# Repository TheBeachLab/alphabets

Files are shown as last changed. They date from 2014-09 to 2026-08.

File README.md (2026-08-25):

<!-- SPDX-FileCopyrightText: 2014-2026 The Beach Lab <https://beachlab.org> -->
<!-- SPDX-License-Identifier: MIT -->
# Alphabets

Welcome to the public repository of the second edition (**V2**) of Alphabets,
an open-source modular split-flap display. Each module shows one character, and
modules can be arranged together to display messages. For information about
the first release from 2014, see [V1](V1). Please also check the [YouTube videos](https://www.youtube.com/playlist?list=PLKDpiLmgp6EuLGCovD-QFxrmyNdrbUmKX)

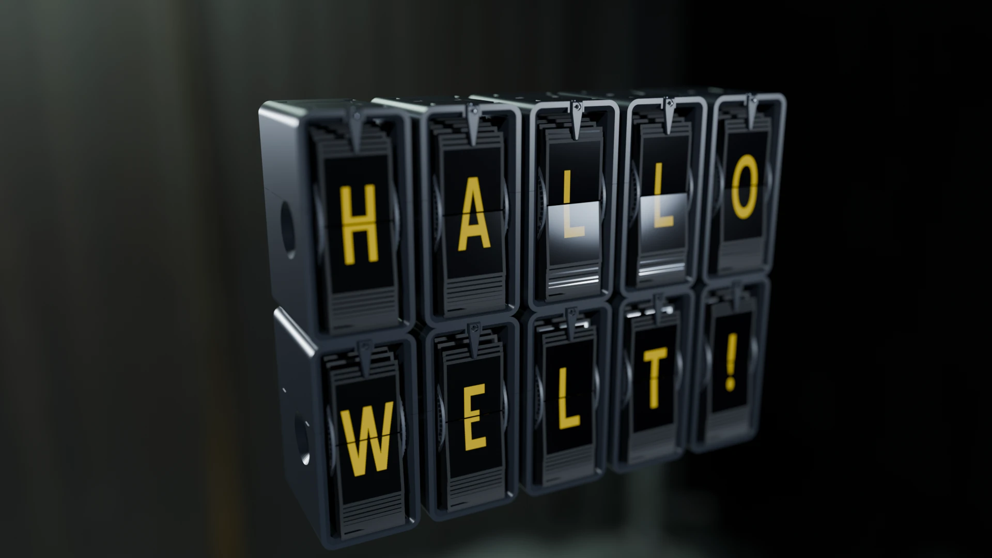
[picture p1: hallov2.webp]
Blender render of ten modular Alphabets V2 split-flap units displaying HALLO WELT!


## The two V2 versions

In this repository you will find two V2 versions: **V2 Prototype** and
**V2 Final**. They are complete, incompatible physical profiles; each has its
own stickers, cards, drum and enclosure, and their parts must not be mixed.

- **V2 Prototype** is for myself. A while ago I printed ten module sticker sets in Dubai and I am using those for prototyping. Of course might use those too. When new V2 Final sticker and card batches are available I will no longer develop this variant.
- **V2 Final** is the supported target for new batches. The expanded character
  map for the German-speaking DACH region (Germany, Austria and Switzerland)
  and Nordic languages requires more vertical artwork space, so this version
  uses taller stickers and cards with a matching drum and enclosure.

See the [V2 physical variants](V2/Hardware/variants/README.md) for the exact parts
and dimensions belonging to each version.

> [!WARNING]
> **UNDER HEAVY DEVELOPMENT — NOT READY FOR USE OR FABRICATION.**
> The V2 Final enclosure has a recorded print check, but the complete mechanism,
> Prototype enclosure, electronics and production process are not physically
> validated. Do not order, print, cut or assemble multiple parts without
> checking the dimensions and validating one complete module. Never mix files
> between the Prototype and Final folders.

## What's new in V2

* 120% pure awesomeness.
* 64 cards with international character set.
* Custom colors: Request custom colored modules and custom characters.
* Build your own or order a kit or ready built module.
* No more gears, direct drive motor
* 3D Printed enclosure
* Entirely designed with widely adopted open source software.
* Assemble in multiple layouts of rows and columns.
* Networked electronics: Connect from one to infinite(*) modules together.
* Web based interface: Control your modules interactively with your web browser.

(*) Not really

## TOC

This table of contents documents V2 Final.

- Mechanical
  - [Cards](doc/cards.md)
  - [Stickers](doc/stickers.md)
  - [Drum](doc/drum.md)
  - [Enclosure](doc/enclosure.md)
- Electronics
  - [Motors](doc/motors.md)
  - [Module Board](doc/module-board.md)
  - [Motherboard](doc/motherboard.md)
  - [Chaining and cables](doc/chaining-and-cables.md)
- Software and Architecture
  - [Protocol](doc/protocol.md)
  - [Module embedded software](doc/module-firmware.md)
  - [Motherboard embedded software](doc/motherboard-firmware.md)
  - [Web interface](doc/web-interface.md)

See the [documentation index](doc/README.md) for the same guide with the
current implementation status of each part.

## License

Except where a file or directory states otherwise, Alphabets' original source
code, firmware, electronics designs, mechanical designs, documentation, and
generated project artifacts are licensed under the [MIT License](LICENSE).
Copyright (c) 2014-2026 [The Beach Lab](https://beachlab.org).

Every commentable file carries a copyright and SPDX license header. JSON,
VS Code workspace, and native KiCad files embed the same fields as document
data so the declaration travels with them. Blender, FreeCAD, OpenType, SVG,
PDF, PNG, JPEG, ZIP, STEP, DXF, binary STL, Gerber, and Excellon files also use
embedded metadata or standard comments and do not need duplicate sidecars.
Only formats without a safely interoperable embedded mechanism use an adjacent
`.license` file. Legacy and bundled third-party sources retain their actual
notices and licenses.

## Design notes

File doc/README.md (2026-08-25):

<!-- SPDX-FileCopyrightText: 2014-2026 The Beach Lab <https://beachlab.org> -->
<!-- SPDX-License-Identifier: MIT -->
# Alphabets V2 guide

[← Project README](../README.md) · [Start with the cards →](cards.md)

Alphabets V2 is an open-source modular split-flap display. Each module shows one
character by turning a drum of 64 cards. Modules can be arranged together to
display complete messages.

## The two V2 versions

This repository contains **V2 Prototype** and **V2 Final**. Each is a complete
physical profile with its own stickers, cards, drum and enclosure, so their
parts cannot be mixed. Prototype uses the ten existing sticker sets printed in
Dubai. Final is the supported target for new batches; its expanded character
map for the German-speaking DACH region (Germany, Austria and Switzerland) and
Nordic languages requires taller artwork, stickers and cards. Prototype support
ends when new Final sticker and card batches are available. The
[physical variants contract](../V2/Hardware/variants/README.md) records the
exact dimensions and files that belong together.

The rest of this guide explains **V2 Final** in the order that information
moves through the display: a message enters the controller, travels through the
module chain, and each module turns its drum until the requested card is
visible.

> [!WARNING]
> V2 is under development. The V2 Final enclosure has a recorded print check,
> but the complete mechanism, Prototype enclosure, electronics and production
> process are not physically validated. Make fit samples and validate one
> complete module before ordering multiple parts.

## Mechanical

1. [Cards](cards.md) — the 64 moving flaps that carry the characters.
2. [Stickers](stickers.md) — the printed character artwork applied to the cards.
3. [Drum](drum.md) — the rotating structure that holds the cards in order.
4. [Enclosure](enclosure.md) — the two-part body around one complete module.

## Electronics

1. [Motors](motors.md) — how one motor advances one drum.
2. [Module board](module-board.md) — the small controller fitted to each module.
3. [Motherboard](motherboard.md) — the planned controller for the complete display.
4. [Chaining and cables](chaining-and-cables.md) — the six-wire ring between boards.

## Software and architecture

1. [Protocol](protocol.md) — the two communication layers and what they carry.
2. [Module embedded software](module-firmware.md) — firmware that moves and homes one drum.
3. [Motherboard embedded software](motherboard-firmware.md) — planned layout and chain control.
4. [Web interface](web-interface.md) — planned user interface for sending text.

## What is implemented now?

| Area | Current repository status |
| --- | --- |
| Cards, stickers, drum, enclosure | Matched Prototype and Final sources and manufacturing exports exist; complete physical validation is still required |
| Motor | A 28BYJ-48 reference model and firmware defaults exist; the real assembly still needs validation |
| Module board | Editable ATtiny1624 KiCad design and fabrication exports exist |
| Module firmware | ATtiny1624 firmware and host-side tests exist |
| Motherboard hardware and firmware | Protocol responsibilities are defined; implementation is not in the repository yet |
| Web interface | Message protocol is defined; implementation is not in the repository yet |

V2 Prototype and V2 Final parts must never be mixed.

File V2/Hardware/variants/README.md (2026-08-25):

<!-- SPDX-FileCopyrightText: 2014-2026 The Beach Lab <https://beachlab.org> -->
<!-- SPDX-License-Identifier: MIT -->
# V2 physical variants

`variants.json` is the authoritative contract that prevents parts from the two
incompatible V2 builds being mixed. A character order is inseparable from its
sticker sheet, card, drum spacing and enclosure source.

V2 Prototipo supports prototyping with the ten existing sticker sets printed in
Dubai. V2 Definitivo is the target profile for new batches. Its expanded DACH
and Nordic character map needs taller artwork, so it uses matched taller
stickers and cards together with the corresponding drum and enclosure.
Prototipo remains usable while the existing sets are in service, but support
ends when new Definitivo sticker and card batches are available.

| Variant | Character preset | Sticker / halves | Card | Drum inner / outer width | Enclosure |
| --- | --- | --- | --- | --- | --- |
| **V2 Prototipo** | `demo-64` | two 50 × 40 mm cuts, 1.8 mm gap | 55 × 43 mm, all visible | 56 / 60.3 mm | one-piece, open-front/rear CadQuery source; physical fit pending |
| **V2 Definitivo** | `international-64` | two 45 × 45.5 mm cuts, 1.8 mm gap | 50 × 48 mm, all visible | 51 / 55.3 mm | current two-piece, open-rear CadQuery source |

Both variants leave a 2.5 mm placement margin at each lateral edge. The sticker
is aligned with the hinge/tab edge, not the opposite free edge. The whole card
face remains visible, with the uncovered strip at the free edge: 3 mm on the
prototype and 2.5 mm on the definitive card.

The `1.8 mm` center gap is part of the printed artwork layout, not a third
sticker. The artwork remains continuous through it, while the cutter receives
two independent half-card rectangles. Typography uses one safe uniform base
scale against the locked sticker width and height, without squeezing or
stretching individual glyphs. W uses the exact Prototype Blue Highway
Condensed outline stored in `cutprint.svg`, with horizontal factor `0.95902088`.
International 64 uses the actual Condensed Æ outline and
a small width adjustment so its final visible width exactly matches W. Both
physical profiles use the exact condensed `%` outline from the Prototype.
The colored background extends `2 mm` past the outer cutter edges without
changing either finished sticker rectangle, preventing white slivers from a
small print/cut registration shift.

## Sticker sheets

V2 Prototype uses the existing
[`cut-print/cutprint.svg`](../Prototype/stickers/cut-print/cutprint.svg) file.
It contains the print artwork and cutter lines used for the ten Dubai sticker
sets.

Generate V2 Final sheets with the locked Definitivo profile:

```sh
python3 V2/Hardware/Final/stickers/generate_stickers.py \
  --variant definitive \
  --color-preset black-white \
  --output-svg /tmp/international-64-definitive-45x91.svg
```

The Final sticker generator records the physical variant in its JSON
manufacturing manifest and rejects an incompatible width or height override.

## Sources and fabrication status

The Prototype CadQuery package is under
[`../Prototype/mechanical`](../Prototype/mechanical/README.md). It defines one
matched card, sticker, drum, pawl and enclosure profile. The Prototype
enclosure is **not yet physically validated**. This profile is supported only
for the existing prototyping batches described above.

Rebuild the Prototype package with:

```sh
cd V2/Hardware/Prototype/mechanical
make check
```

The Final variant is the supported target for new sticker and card batches. Its
enclosure is confirmed against the 2026-08-23 physical print. Its card
and 64-position drum are generated from
`V2/Hardware/Final/mechanical/alphabets_cad/`, and its sole current enclosure is
the capture-fitted pipeline under
`generated/captured-enclosure/`. Further fit observations are required before
a production run.

Both card substrates are 0.5 mm. A 0.1 mm sticker is applied to each face,
making the covered area 0.7 mm thick; the opposite free-edge strip, lateral
margins and tab extensions remain bare at 0.5 mm.

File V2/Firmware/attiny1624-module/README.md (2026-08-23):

<!-- SPDX-FileCopyrightText: 2014-2026 The Beach Lab <https://beachlab.org> -->
<!-- SPDX-License-Identifier: MIT -->
# ATtiny1624 module firmware

This AVR C firmware implements revision 2 of the controller-to-module
[`protocol`](../../Protocol/PROTOCOL.md) for a 5 V ATtiny1624-SSU module.

## Implemented behavior

- Hardware `SPI0` client on `PA1/MOSI`, `PA2/MISO`, `PA3/SCK`, and `PA4/SS`.
- Byte forwarding through an arbitrary-length physical module chain.
- `0x00`, `0x01..0x40`, and automatic-home `0x41` commands.
- Active-low position-0 sensor on `PA5` with the internal pull-up enabled.
- Edge-qualified and sample-confirmed homing from either initial sensor state
  with a two-revolution travel limit.
- Present, ready, and current-position status reporting.
- Non-blocking forward-only half-step motion on `PB0..PB3` using `TCB0`.
- Wear-levelled EEPROM persistence with invalidation before movement.
- Idle sleep while SPI, latch, and motor interrupts remain serviceable.

All modules use the same binary. Chain order determines display position.

## Pin assignment

| Function | Port | SOIC-14 pin |
| --- | --- | --- |
| `LATCH / SPI0 SS` | `PA4` | 2 |
| `HOME`, active low | `PA5` | 3 |
| Motor phase 4 | `PB3` | 6 |
| Motor phase 3 | `PB2` | 7 |
| Motor phase 2 | `PB1` | 8 |
| Motor phase 1 | `PB0` | 9 |
| `UPDI` | `PA0` | 10 |
| `DATA_IN / SPI0 MOSI` | `PA1` | 11 |
| `DATA_OUT / SPI0 MISO` | `PA2` | 12 |
| `CLOCK / SPI0 SCK` | `PA3` | 13 |

The home input expects a contact or open-drain sensor between `PA5` and ground.
The motor outputs drive a ULN2003-style input stage, not the motor coils
directly. Keep the UPDI pad accessible on the production PCB.

## Position recovery

On first boot or after an interrupted movement, position commands remain
disabled until the controller sends `0x41`. The module advances forward until
it observes a fresh inactive-to-active home transition, stores position 0, and
then reports ready. If the transition is not found within two configured drum
revolutions, the phases are released and the module remains unreferenced.

The EEPROM journal contains 32 four-byte records. The firmware appends an
unknown-position record before energizing the motor and appends the completed
position after stopping. The commit byte is written last so an interrupted
write cannot become the active record.

## Motor configuration

The defaults target a 5 V 28BYJ-48 with a ULN2003-style driver:

| Setting | Default | Meaning |
| --- | --- | --- |
| `F_CPU` | `20000000UL` | Factory 20 MHz oscillator with its prescaler disabled |
| `MOTOR_HALF_STEPS_PER_REVOLUTION` | `4096UL` | Tunable output-shaft half-steps per drum revolution |
| `MOTOR_STEP_HZ` | `500UL` | Half-step rate |
| `MOTOR_REVERSED` | `0` | Set to `1` to reverse the phase sequence |
| `HOMING_MAX_REVOLUTIONS` | `2UL` | Maximum home-search travel |
| `HOME_ACTIVE_CONFIRM_STEPS` | `2u` | Consecutive active samples required at home |

The firmware distributes `MOTOR_HALF_STEPS_PER_REVOLUTION` across all 64 drum
positions, including values that are not divisible by 64. Confirm the actual
step count and direction on the assembled mechanism.

Override settings through `CPPFLAGS`, for example:

```sh
make CPPFLAGS='-DF_CPU=20000000UL -DMOTOR_HALF_STEPS_PER_REVOLUTION=4076UL -DMOTOR_REVERSED=1'
```

## Build and test

Run the portable state-machine and ring tests with the host compiler:

```sh
make test
```

Build the ATtiny1624 ELF and Intel HEX with AVR GCC:

```sh
make
```

With the keg-only Homebrew AVR GCC 15 package used for repository validation:

```sh
PATH="/opt/homebrew/opt/avr-gcc@15/bin:$PATH" make check
```

The resulting image is
`build/alphabets-v2-attiny1624-module.hex`.

Flash it through the board's UPDI connection with an avrdude programmer that
supports the ATtiny1624, for example an Atmel-ICE:

```sh
make flash PROGRAMMER=atmelice_updi
```

Use `AVRDUDE_FLAGS` for programmer-specific port settings. The firmware selects
the undivided clock at runtime and expects the factory `OSCCFG.FREQSEL=0x2`
[setting for 20 MHz](https://onlinedocs.microchip.com/oxy/GUID-7056F141-DF07-46C5-A4B8-97EB46E9B945-en-US-12/GUID-7BAFED36-9153-4AA6-BB14-C0434476E4F6.html).
After a chip erase that clears EEPROM, run `0x41` once to establish the drum
reference.

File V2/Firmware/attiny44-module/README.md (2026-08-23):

<!-- SPDX-FileCopyrightText: 2014-2026 The Beach Lab <https://beachlab.org> -->
<!-- SPDX-License-Identifier: MIT -->
# ATtiny44A module firmware

This AVR C firmware implements the controller-to-module protocol in
[`prototype protocol`](../../Protocol/PROTOCOL_V1_ATTINY44.md) for the
[`ATtiny44 ring board`](../../Hardware/Prototype/electronics/attiny44-ring)
board.

## Implemented behavior

- ATtiny44A USI three-wire slave on `PA6/DI`, `PA5/DO`, and `PA4/USCK`.
- `PA7` pin-change interrupt for the active-low frame `LATCH`.
- Byte forwarding through an arbitrary-length physical module chain.
- Rejection of frames that end between byte boundaries.
- `0x00`, `0x01..0x40`, and `0x41` command handling.
- Present, ready, and current-position status byte generation.
- Non-blocking forward-only half-step motion on `PA0..PA3`.
- Timer-driven movement while USI frames continue to be serviced.
- Wear-levelled EEPROM persistence of the last fully reached position.
- EEPROM invalidation before movement, so interrupted motion requires a new
  manual position-0 reference instead of reporting a stale position as ready.

All modules use the same binary. Chain order determines display position.

## Position reference on the current PCB

The current `attiny44-ring` PCB leaves `PB2/HOME` unconnected. On first boot,
after interrupted motion, or after mechanically changing a drum:

1. Leave the module powered and stationary.
2. Align the drum so its installed character position 0 is visible.
3. Send command `0x41` to that module.
4. Wait until its status reports `ready = 1` at position 0.

The calibration command records the reference in EEPROM without moving the
motor. Position commands are ignored while the reference is unknown.

Position state uses a 32-record EEPROM journal. The firmware appends an
unreferenced record before energizing the motor and appends the completed
position afterward. The commit byte is written last, so a partially written
record is ignored at the next boot.

## Motor configuration

The defaults target a 5 V 28BYJ-48 with its ULN2003-style driver:

| Setting | Default | Meaning |
| --- | --- | --- |
| `F_CPU` | `8000000UL` | Internal CPU clock after clearing `CLKPR` |
| `MOTOR_HALF_STEPS_PER_REVOLUTION` | `4096UL` | Tunable output-shaft half-steps per drum revolution |
| `MOTOR_STEP_HZ` | `500UL` | Half-step rate |
| `MOTOR_REVERSED` | `0` | Set to `1` to reverse the phase sequence |

The firmware distributes `MOTOR_HALF_STEPS_PER_REVOLUTION` across all 64 drum
positions, including values that are not divisible by 64. Confirm the actual
step count and direction on the assembled mechanism before running long message
sequences.

Override a setting through `CPPFLAGS`, for example:

```sh
make CPPFLAGS='-DF_CPU=8000000UL -DMOTOR_HALF_STEPS_PER_REVOLUTION=4076UL -DMOTOR_REVERSED=1'
```

## Build and test

Run the portable protocol state-machine tests with the host C compiler:

```sh
make test
```

The tests cover command/status behavior, forward wraparound, fractional motor
steps, and command/status ordering plus discovery for 1, 4, 16, and 255
modules.

Build the ATtiny44A ELF and Intel HEX with AVR GCC:

```sh
make
```

With the keg-only Homebrew AVR GCC 15 package used for repository validation:

```sh
PATH="/opt/homebrew/opt/avr-gcc@15/bin:$PATH" make check
```

Flash through the board's AVR ISP connector:

```sh
make flash PROGRAMMER=usbtiny
```

The flash target requires `avrdude`. `AVRDUDE_FLAGS` can provide a port or other
programmer-specific settings. The target does not change fuses. The firmware
selects the undivided internal 8 MHz clock at runtime through `CLKPR`.

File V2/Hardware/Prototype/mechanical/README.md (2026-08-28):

<!-- SPDX-FileCopyrightText: 2014-2026 The Beach Lab <https://beachlab.org> -->
<!-- SPDX-License-Identifier: MIT -->
# Alphabets V2 Prototype mechanical CAD

[← Prototype stickers](../stickers/README.md) · [Physical variants](../../variants/README.md) · [Final CAD →](../../Final/mechanical/README.md)

This directory is the CadQuery manufacturing source for **V2 Prototype**. It
generates the matched Prototype card, drum, pawl and one-piece enclosure.
Prototype and Final parts must not be mixed.

This profile supports prototyping with the ten existing sticker sets printed in
Dubai. It remains usable while those sets are in service, but support ends when
new V2 Final sticker and card batches are available. V2 Final is the target for
new batches and carries the taller DACH/Nordic character set.

Prototype enclosure and mechanism

## Matched Prototype profile

| Part | Prototype value |
| --- | ---: |
| Character order | `demo-64` |
| Card body | 55 × 43 × 0.5 mm |
| Card including tabs | 63 × 43 mm |
| Tab | 4 × 3 mm on each side |
| Sticker sheet item | 50 × 80 mm, cut at 40 mm |
| Sticker on each card face | 50 × 40 × 0.1 mm |
| Drum | 64 positions, 85 mm diameter |
| Drum inner / outer width | 56 / 60.3 mm |
| Visible pawl | Prototype, 6 mm extension parameter |

The sticker starts 3 mm from the card's free edge and reaches the hinge edge.
The complete 43 mm card remains visible; the 3 mm free-edge strip is simply
unstickered.

## Enclosure and validation

`reference/cards-position-capture-final.json` supplies the settled card
orientations at frame 27464. CadQuery rebuilds the Prototype cards, stickers,
drum, pawl and enclosure from this directory's `design.toml`, then places the
cards at those orientations.

The enclosure is **not yet physically validated**. Print one complete Prototype
module and check the real card motion, pawl, motor, shaft, stacking features and
cable clearance before reproducing it.

The Prototype card has one explicit fit exception: the
corner radius of a rectangular 3 × 0.5 mm tab is about 1.5207 mm, approximately
0.0207 mm larger than the radius of its nominal 3 mm pivot hole. The model
records this as `allow_tab_interference = true`; it does not claim theoretical
rotation clearance. Confirm the real material, kerf and hole fit with a small
sample.

## Rebuild and test

CadQuery 2.8.0 runs under Python 3.12:

```sh
cd V2/Hardware/Prototype/mechanical
make setup
make check
```

To reuse another compatible environment:

```sh
make check PYTHON=/path/to/python
```

`make generate` creates the Prototype card, drum, motor references and neutral
manufacturing files. `make generate-captured-enclosure` creates the one-piece
enclosure, Prototype pawl, assembly, review image and a two-object Bambu Lab A1
Mini plate. The enclosure prints standing on its front rim, with the pawl
inside the open area of the same plate. `make verify-generated` regenerates
everything and fails if the committed outputs are stale.

## View and adjust

All direct dimensions are in [`design.toml`](design.toml). Derived dimensions
are calculated in `alphabets_cad/parameters.py`, so card, drum and enclosure
widths cannot silently drift apart.

The primary `[drum_enclosure]` controls use the drum centre as their origin:

| Parameter | Meaning |
| --- | --- |
| `top_distance` | Drum centre to the inside of the top wall |
| `bottom_distance` | Drum centre to the inside floor |
| `back_distance` | Drum centre to the inside back edge |
| `side_clearance` | Gap from each outside drum face to its inside enclosure wall |
| `wall_thickness` | Enclosure thickness on the sides, top and bottom |
| `side_inset_depth` | Depth of both full-side pockets |
| `side_pocket_chamfer` | 45-degree lead-in depth at both pocket openings |
| `side_pocket_margin` | Structural rim around every pocket opening |
| `side_pocket_corner_radius` | Radius at both rounded pocket openings |
| `electronics_card_center_y` | PCB centre; negative values move it toward the back |
| `electronics_card_center_z` | PCB centre height relative to the drum axis |

The front follows the saved front-card/pawl plane. `front_chamfer` is derived
as `wall_thickness / 2`, and the material left behind both side pockets is
`wall_thickness - side_inset_depth`. The pawl screw clearance and matching
enclosure pilot share the exact midpoint of the flat top-wall land (3 mm from
either face with the current 6 mm wall). The pawl has no screw-head recess.

Both enclosure faces use the same large rounded-rectangle pocket. The pocket
shape is independent of the electronics envelope, so
`electronics_card_center_y` and `electronics_card_center_z` can move the board
anywhere that fits within the recessed side tray.

The enclosure is one continuous shell. It has no horizontal assembly seam,
magnet pockets or internal alignment keys. Four external truncated pyramids on
the bottom and their four top sockets align complete modules when stacked.

Captured card angles come from the settled Blender snapshot, while every card
tab axis is rebuilt on the exact calculated centre of its rotated drum hole.
The Prototype viewer does not inherit Blender hinge-constraint drift or the
different centroid of the Final card used by that snapshot.

For VS Code with OCP CAD Viewer:

```sh
make setup-vscode
code alphabets-prototype-mechanical.code-workspace
```

Run `view_enclosure_vscode.py`. The groups include `enclosure`,
`pua_prototipo`, `tambor`, `cards`, `stickers`, `motor`, `electronics` and
`envelopes`; the Final pawl starts hidden. CQ-editor users can run `make gui`
or `make gui-enclosure`.

## Generated fabrication files

- `generated/cut/flap-card.dxf`: Prototype card cutter profile.
- `generated/step/flap-card.step`: neutral 3D card model.
- `generated/cut/drum-*.dxf`: matched 56 mm internal-width drum parts.
- `generated/captured-enclosure/print/`: one-piece enclosure STL, Prototype
  pawl and two-object A1 Mini plate.
- `generated/captured-enclosure/step/`: enclosure, pawl and assembly STEP.
- `generated/manifest.json` and `generated/captured-enclosure/manifest.json`:
  exact dimensions, bounds, source files and validation boundary.

The matching Demo‑64 artwork and cutter files are in
[`../stickers/generated`](../stickers/README.md).

[← Prototype stickers](../stickers/README.md) · [Physical variants](../../variants/README.md) · [Final CAD →](../../Final/mechanical/README.md)

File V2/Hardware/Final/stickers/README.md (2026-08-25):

<!-- SPDX-FileCopyrightText: 2014-2026 The Beach Lab <https://beachlab.org> -->
<!-- SPDX-License-Identifier: MIT -->
# V2 sticker generator

`generate_stickers.py` builds a complete vector sticker sheet from the same
64-position character profile used by the controller. The default output is
the `international-64` profile with white letters on black. Glyphs are written
as vector paths in both SVG and PDF, so the production files do not depend on
fonts installed on the computer or printer.

Install its two Python dependencies once:

```sh
python3 -m pip install -r V2/Hardware/Final/stickers/requirements.txt
```

## V2 Final physical profile

Use the locked Definitivo profile for V2 Final fabrication. See
[`../../variants/`](../../variants/README.md) for the full sticker, card, drum
and enclosure contract.

```sh
python3 V2/Hardware/Final/stickers/generate_stickers.py \
  --variant definitive \
  --output-svg /tmp/international-64-definitive-45x91.svg
```

`--variant` fixes the character preset, sticker width, sticker height, cut gap,
and `2 mm` background bleed, and records them in the JSON manifest. It refuses
a conflicting physical override. V2 Prototype fabrication uses the existing
[`../../Prototype/stickers/cut-print/cutprint.svg`](../../Prototype/stickers/cut-print/cutprint.svg)
print-and-cut artwork.

## Print bleed and cutter geometry

The SVG is accompanied by a JSON manufacturing manifest containing the exact
character order, colors, finished cut dimensions, `2 mm` background bleed and
font checksum. The background extends `2 mm` beyond every outer cutter edge,
so a small registration shift cannot expose white material. The artwork also
remains uninterrupted across the intentional center gap while the cutter
geometry contains two independent rectangles. The magenta sticker
outlines are superimposed vector paths in the print SVG and PDF by default,
matching the production file. `--no-guides` produces clean artwork when
required, while `--output-cut-svg` writes the same two-rectangle cutter
geometry as a separate SVG.
Every vector glyph is clipped to its own sticker boundary and uses the non-zero
winding rule in SVG and PDF, avoiding inverted areas where the outlines
overlap. In SVG, the clipping is applied to an outer group in sheet coordinates
so macOS Quick Look renders the transformed glyph paths correctly.

These lines cut the rectangular stickers; they are not the physical flap/card
die. The card die includes the two drum tabs and is generated separately in
[`../cards/`](../cards/README.md).

Every visible character uses one shared **uniform** scale and baseline. The
largest safe uniform scale is selected against both locked sticker dimensions;
no character is squeezed or stretched on one axis. `W` uses the exact Blue
Highway Condensed outline stored in the Prototype `cutprint.svg` source and an
additional `0.95902088` horizontal factor. Each visible outline is geometrically
centered in its equal-sized artwork cell; proportional advance widths do not
change the card size. No glyph receives an individual vertical offset.

The matched **V2 Definitivo** geometry uses two `45 × 45.5 mm` cuts separated
by a `1.8 mm` printed gap. The locked cut width remains `45 mm`; the complete
cut-aligned artwork cell is therefore `45 × 92.8 mm`, while its colored
background bounds are `49 × 96.8 mm` after the `2 mm` bleed on every outer
side. Each sticker is centred laterally on the complete
`50 × 48 mm` visible face and aligned to its hinge/tab edge. The opposite
2.5 mm strip remains unstickered. The center-cut edge of each half is the edge
that must face the tabs. Skipping the `1.8 mm` printed interval between the two
cuts compensates the physical separation and preserves continuous curves and
diagonal strokes. Generate it without changing the shared alignment with:

```sh
python3 V2/Hardware/Final/stickers/generate_stickers.py \
  --variant definitive \
  --output-svg /tmp/international-45x91.svg \
  --output-cut-svg /tmp/international-45x91-cut.svg \
  --output-pdf /tmp/international-45x91.pdf
```

`--horizontal-padding` and `--vertical-padding` reduce the safe area available
to the uniform scale; neither option deforms the type. Generic experiments can
override the background extension with `--bleed`, but physical variants lock
it to their declared manufacturing value.

The matching card cutter and 51 mm drum separation are documented in
[`../cards/`](../cards/README.md).

## Color presets

| Preset | Background | Letters |
| --- | --- | --- |
| `black-white` (default) | black | white |
| `black-yellow` | black | yellow |
| `yellow-black` | yellow | black |
| `white-black` | white | black |

Select one with, for example, `--color-preset yellow-black`. Any preset can be
overridden with exact RGB values:

```sh
python3 V2/Hardware/Final/stickers/generate_stickers.py \
  --background '#14213D' --foreground '#FCA311' \
  --output-svg /tmp/my-stickers.svg --output-pdf /tmp/my-stickers.pdf
```

Colors use `#RRGGBB`. Yellow is `#FFCC00`.

Generate the four production color variants at 45 × 91 mm with:

```sh
for preset in black-white black-yellow yellow-black white-black; do
  python3 V2/Hardware/Final/stickers/generate_stickers.py \
    --variant definitive \
    --color-preset "$preset" \
    --output-svg "V2/Hardware/Final/stickers/generated/international-64-${preset}-45x91.svg" \
    --output-pdf "V2/Hardware/Final/stickers/output/pdf/alphabets-international-64-${preset}-45x91-stickers.pdf"
done

# The cutter geometry is color-independent, so one current cut file is enough.
python3 V2/Hardware/Final/stickers/generate_stickers.py \
  --variant definitive \
  --color-preset black-white \
  --output-svg /tmp/international-64-black-white-45x91.svg \
  --output-cut-svg V2/Hardware/Final/stickers/generated/international-64-black-white-45x91-cut.svg
```

These commands produce the complete current `45x91` Final artifact set.

## Preset or custom characters

A `--preset` or settings file remains available for non-fabrication
experiments:

```sh
python3 V2/Hardware/Final/stickers/generate_stickers.py \
  --settings V2/Hardware/Final/stickers/settings.example.json \
  --output-svg /tmp/custom-stickers.svg
```

Custom profiles must pass the shared validation: exactly 64 unique printable
characters and exactly one ASCII space. The generator stops before writing
production files if any selected font cannot render a required character.

## Typeface

The generator uses the traceable **BlueHighwayD-International** hybrid. It
contains the Blue Highway D outlines and supplies the two characters missing
from that source through documented fallbacks. The Final profile uses the exact
Blue Highway Condensed W outline stored in the Prototype `cutprint.svg`
fabrication file.
International 64 also uses the Condensed Æ outline
from Typodermic's official
[CC0 Blue Highway package](https://typodermicfonts.com/public-domain/). Its
final horizontal factor makes its visible width exactly match the transformed
W. The Final profile also uses the exact condensed `%` outline stored in
Prototype `cutprint.svg`. No locally installed font is required for these
overrides.

The alignment model follows the lesson from Scott Bezek's production
[splitflap generator](https://github.com/scottbez1/splitflap/blob/master/3d/flap_fonts.scad):
font scale and position are explicit manufacturing parameters. This generator
uses one global uniform base scale and baseline for the entire profile, with
each font outline centered inside the common physical card. The documented W
and Æ horizontal factors are applied after that base scale. Exact provenance
and checksums are recorded in [`fonts/`](fonts/README.md).

Choose another OpenType font with `--font path/to/font.otf`. For a variable
font, select its weight and width with `--font-weight 600 --font-width 80`.
The generator rejects the font unless that single file covers every selected
character. The manifest records the resolved file, variation, spacing model,
shared baseline/scale, advance range and SHA-256 checksum.

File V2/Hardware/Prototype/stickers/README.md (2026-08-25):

<!-- SPDX-FileCopyrightText: 2014-2026 The Beach Lab <https://beachlab.org> -->
<!-- SPDX-License-Identifier: MIT -->
# V2 Prototype stickers

[← Prototype mechanical CAD](../mechanical/README.md) · [Physical variants](../../variants/README.md) · [Shared generator →](../../Final/stickers/README.md)

V2 Prototype uses the **Demo 64** character order and two nominal `50 × 40 mm`
sticker cuts. The cuts are separated by a `1.8 mm` printed gap,
so each uninterrupted cut-aligned artwork cell is `50 × 81.8 mm`. Its colored
background extends `2 mm` past the outer cut lines, producing `54 × 85.8 mm`
background bounds without changing either finished sticker. Each face is
centred on a 55 × 43 mm card, leaving 2.5 mm at each side and an unstickered
3 mm strip at the free edge.

Prototype print-and-cut sticker sheet

## Exact character order

```text
ABCDEFGHIJKLMNOPQRSTUVWXYZ:.0123456789$€&@%×/·#=*+-±()<>,'°■£~©␠
```

There are exactly 64 unique positions. `␠` above denotes the final ASCII space.
This order must match the physical cards and controller mapping.

## Current fabrication file

Use [`cut-print/cutprint.svg`](cut-print/cutprint.svg) to print and cut the
Prototype stickers. It is the fabrication artwork used for the ten sticker sets
printed in Dubai and contains both the colored vector artwork and cutter lines.

## Typeface

The fabrication artwork contains vector outlines, so printing does not depend
on fonts installed on the printer's computer. Its `W` and `%` use the condensed
Blue Highway outlines visible in the file.

[← Prototype mechanical CAD](../mechanical/README.md) · [Physical variants](../../variants/README.md) · [Shared generator →](../../Final/stickers/README.md)

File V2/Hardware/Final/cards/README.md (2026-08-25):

<!-- SPDX-FileCopyrightText: 2014-2026 The Beach Lab <https://beachlab.org> -->
<!-- SPDX-License-Identifier: MIT -->
# V2 Definitivo card and drum width

This directory contains the **V2 Definitivo** 50 mm card files. The complete
physical contract for both incompatible V2 variants is in
[`../../variants/`](../../variants/README.md).

The production card uses one half of the `45 × 91 mm` sticker sheet:

- visible body: the complete central `50 × 48 mm` surface;
- total card: `50 × 48 mm`;
- side tabs: `4 × 2.5 mm` each; their bare `0.5 mm` thickness is included in the
  pivot fit, leaving at least `0.15 mm` radial clearance in the `3 mm` holes;
- total width across the tabs: `58 mm`;
- black card substrate: `0.5 mm`;
- sticker face: `45 × 45.5 mm`, centred with `2.5 mm` lateral margin and aligned
  to the hinge/tab edge, leaving the opposite 2.5 mm strip bare;
- one `0.1 mm` sticker on each face, for `0.7 mm` finished body thickness;
- the visible colour comes from the sticker, not from the substrate model.

The two drum sides are separated by `51 mm`: the `50 mm` card body plus
`1 mm` total axial clearance. The drum keeps its `85 mm` diameter and all 64
flap positions.

## Manufacturing source

The complete V2 Final mechanical model is in
[`../mechanical/`](../mechanical/README.md). It produces the current
DXF and STEP together with the matching drum and validates their shared
dimensions automatically. The committed files in this directory provide the
same Final card as an editable FreeCAD model and standalone cutter outline.

## Card files

The FreeCAD document properties record The Beach Lab as creator and company,
identify the licence as MIT, link to the repository licence, and repeat the SPDX
copyright and licence identifiers in the document comment. This metadata stays
inside an `.fcstd` or `.FCBak` file when it is shared separately.

- `card-50x48.fcstd`: editable FreeCAD model and dimensional parameter sheet;
- `card-50x48-cut.svg`: exact vector cutter outline in millimetres;
- `card-50x48-cut.dxf`: the same closed outline on the `CUT` layer;
- `card-50x48.json`: manufacturing dimensions and the card/sticker/drum match.

Regenerate the Final FreeCAD files from the repository root with:

```sh
/Applications/FreeCAD.app/Contents/Resources/bin/FreeCADCmd \
  V2/Hardware/Final/cards/generate_card.py --pass '--variant definitive'
```

The Prototype card and its 56 mm drum are generated by the separate
[`../../Prototype/mechanical/`](../../Prototype/mechanical/README.md) CadQuery
package.

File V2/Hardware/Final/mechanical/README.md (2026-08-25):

<!-- SPDX-FileCopyrightText: 2014-2026 The Beach Lab <https://beachlab.org> -->
<!-- SPDX-License-Identifier: MIT -->
# Alphabets V2 Definitivo mechanical CAD

This directory is the CadQuery manufacturing source for **V2 Definitivo**: the
50 mm card, 51 mm internal drum width and two-piece enclosure with open front
and rear. The incompatible 55 mm **V2 Prototipo** is generated by
[`../../Prototype/mechanical/`](../../Prototype/mechanical/README.md). The
complete split is recorded in [`../../variants/`](../../variants/README.md).

V2 Definitivo is the supported target for new sticker and card batches. Its
taller card and artwork profile carries the expanded DACH and Nordic character
map. V2 Prototipo remains available for the ten existing sticker sets printed
in Dubai until replacement batches are available.

`design.toml` is the editable source for direct Final dimensions. CadQuery
calculates the dependent geometry and produces vendor-neutral manufacturing
exports without GUI interaction.

## Included geometry

| CadQuery model | Purpose | Validation status |
| --- | --- | --- |
| 50 × 48 mm flap card | Cutter and assembly geometry | Current dimensional manufacturing source; test material and kerf |
| 64-position, 51 mm inner-width drum | Laser-cut cutter and assembly geometry | Current dimensional manufacturing source; test material, kerf and card clearance |
| Lightweight printed spool | Optional additive drum | Physical validation required |
| 28BYJ-48 motor | Clearance envelope | Reference only; measure the selected motor |
| Holder side and inset | Optional holder geometry | Physical validation required |
| Enclosure sketch | Non-solid reference geometry | Not a manufacturing part |
| Two-part drum enclosure | Printable Final module body | Print checked; complete mechanism and production run still require validation |

## Current printed enclosure

The current enclosure design review uses Blender frame `27464`, controller position `37`,
from `../blender/generated/cards-position-capture.json`. This is the sole
current enclosure pipeline and the model shown by `view_enclosure_vscode.py`.
The latest physical print was confirmed against this viewer on 2026-08-23.
It derives its asymmetric cavity from the actual card envelope, the saved
compression floor and the fixed pawl. The floor top is authoritative at
`Z = -75 mm`; the four cards that Bullet left slightly below that plane do not
increase the enclosure height.

The captured enclosure body is approximately 78.01 mm wide, 109.05 mm deep and
159.31 mm high. Its 8 mm walls grow outward from the captured cavity and use a
10 mm external corner radius. It is a hollow tube with no front or rear wall
and no screw lugs. A 4 mm chamfer runs around the inner edge of the front rim,
stopping at a flat 14 mm-wide land for the pawl. The outside front edge remains
square. The viewer renders the enclosure fully opaque.

The front pawl is a separate 2 mm-thick part seated flush against the front
edge of the upper wall. Its isosceles blade uses the full 10 mm screw-pad width
and ends in a broader 2 mm-radius rounded tip. Its outward face has a 1 mm
chamfer around the external profile, while the screw bore remains cylindrical.
A straight 6 mm diameter × 1 mm deep counterbore receives the M3 screw head.
The screw passes through its 3.4 mm clearance hole and self-taps into a 2.6 mm
pilot extending 8 mm into the upper enclosure. The
definitive pawl retains the captured rounded-tip support height; the alternative
prototype pawl extends 5 mm farther down to compensate for the 43 mm card in
place of the definitive 48 mm card. Both export separately, while the viewer
shows the definitive pawl by default.

The lower half replaces the fragile printed shaft with a 2.6 mm M3
self-tapping pilot in a 9 mm boss. A user-supplied M3 screw becomes the axle
through the shaft-side disc's 3.4 mm clearance hole, and the boss stops 0.5 mm
before the acrylic disc. Its head sits in a straight 6 mm diameter × 2 mm deep
counterbore on the recessed outside face. The horizontal split is 12 mm above
the drum axis, so
this support stays entirely in the lower half. Four 3 mm-high truncated
pyramids with 45 degree sides align both halves; their upper sockets include
0.2 mm clearance. Four additional downward-facing pyramids on the enclosure
base engage four matching sockets in the top of the module below, using the
same 3 mm height, 45 degree sides and 0.2 mm socket clearance.
Their 8 mm bases are inset to the tangent of the enclosure's 10 mm corner
radius, so no stacking pivot starts on the rounded area.

The motor is inset 6 mm into a cleared mounting pocket and is retained by two
2.6 mm M3 self-tapping pilots in internal bosses. The blue backpack envelope
has an extra 1 mm cable clearance. A 50 × 35 mm electronics-card envelope sits
below the motor in the same side recess. Both fit inside one approximately
55.7 × 76.6 mm
rounded rectangle with an 8 mm inner corner radius and one continuous 6 mm
lead-in. The opposite outside wall has a matching
6 mm motor chassis recess, so both sides retain 2 mm of the original 8 mm wall.
Both lateral recesses expand through
6 mm-long, 45 degree lead-ins toward the outside; the remaining 2 mm motor bore
uses the same supportless transition while screw pilots stay cylindrical. The
three internal mounting bosses taper continuously from the inside wall to
their free ends; no exposed cylindrical segment remains. Their M3 pilot bores
remain straight and unchanged. These
features do not produce zero-gap docking: the current motor still needs
approximately 7.3 mm between enclosure bodies, for a minimum pitch of about
85.31 mm.

The upper face carries a large lowercase `α`, rotated to read toward the
enclosure front. It is split
horizontally by a 2 mm material band, like the two halves of a split-flap
character, and recessed 0.2 mm through a nominal 0.2 mm lead-in. The outline
uses the existing `Overpass Mono Medium` font asset from the sticker workflow.
Each lateral wall also carries one centred pair of straight cylindrical magnet
inserts at the split, halfway between the front and rear alignment frustums:
3.4 mm diameter × 1.2 mm deep for nominal 3 × 1 mm magnets. The extra 0.4 mm
diameter and 0.2 mm depth compensate for undersized FDM holes. These are
joined by one identically compensated insert at the centre of the top `α` and
one aligned insert in the module base, producing a light magnetic click when
modules are stacked vertically. All magnet locations are derived review
dimensions, not
hand-entered constants; changing the capture or clearance parameters rebuilds
the solids.

Generate its separate STEP, STL, SVG and manifest files with:

```sh
make generate-captured-enclosure
```

The same command also exports
`generated/captured-enclosure/print/captured-enclosure-bambu-a1-mini-four-part-plate.stl`.
This single STL contains the upper enclosure, lower enclosure and both pawls
inside the A1 mini's 180 × 180 × 180 mm build volume. The enclosure halves sit
on their front rims, as required by the supportless side chamfers; both pawls
sit on their flat rear faces so the screw-head counterbores face upward. The
two enclosure halves retain their assembled alignment on the plate, separated
by only 2 mm at the split. The resulting narrow layout is centred laterally and
reduces carriage travel. Both pawls nest inside the open area of the lower half
rather than extending the occupied footprint.

## Rebuild

CadQuery 2.8.0 is pinned and runs under Python 3.12:

```sh
cd V2/Hardware/Final/mechanical
make setup
make check
```

To use an existing environment:

```sh
make check PYTHON=/path/to/python
```

`generate.py` rebuilds the Final card, drum, motor, and reference artifacts.
The current enclosure is rebuilt separately by `generate-captured-enclosure`.
Run the Prototype generator from `V2/Hardware/Prototype/mechanical`; this Final
generator rejects `--variant prototype` so the two profiles cannot be mixed.

## Graphical editing

Open the complete reference module in CQ-editor from this directory:

```sh
make gui
```

Open the capture-fitted enclosure and settled mechanism with:

```sh
make gui-enclosure
```

The enclosure view uses the same saved settled positions and enclosure
components as the OCP viewer and fabrication exporter. It shows the definitive
pawl by default and keeps the prototype pawl available as a separate object.

Each face sticker is a separate yellow viewer object named
`sticker_00_front`, `sticker_00_back`, through `sticker_63_front` and
`sticker_63_back`. The black substrate remains a separate `card_XX` object, so
character artwork can later be assigned without losing the physical layers.
With this numbering, character position `i` uses `card_i_front` for its lower
half and `card_(i+1 mod 64)_back` for its upper half. Thus the blank uses
`sticker_00_front` plus `sticker_01_back`, `A` uses `sticker_01_front` plus
`sticker_02_back`, and the final degree sign wraps from `sticker_63_front` to
`sticker_00_back`.

Each card uses a 0.5 mm blank with one centred 45 × 45.5 × 0.1 mm sticker on
each face. The paired sticker artwork is cut through its center so curves and
diagonals continue across the displayed halves. Each sticker is aligned to the
hinge/tab edge; the opposite free-edge strip remains bare. The covered area is
0.7 mm thick; that 2.5 mm strip, lateral margins and tab extensions remain
0.5 mm. Cards are shown black because their visible colour comes from the
sticker.

`design.toml` is the committed source for every direct manufacturing dimension.
Derived values — for example the drum's inner width and the enclosure's overall
width — remain calculated by the model and cannot drift. `view.py` exposes the
resolved `parameters`, each named shape in `objects`, and the export assembly in
`result`. CQ-editor therefore shows the parts separately instead of one opaque
assembly.

For a fit or fabrication variant, create a small TOML file containing only the
dimensions that change, then use the same profile for preview and export:

```sh
make gui PROFILE=profiles/fit-check.toml
make generate PROFILE=profiles/fit-check.toml OUTPUT=generated/fit-check
```

The profile is applied over the committed design, and unknown section or field
names fail immediately instead of silently changing the model.

### VS Code viewer

OCP CAD Viewer is the preferred interactive viewer: it inherits VS Code's
theme, provides per-object selection and visibility, and renders this model
through `view_vscode.py`. Run `view_enclosure_vscode.py` for the captured
two-part enclosure, settled 64-card mechanism, stickers, motor and envelope
references grouped as `enclosure`, `pua_definitiva`, `pua_prototipo`, `tambor`,
`cards`, `stickers`, `motor` and `envelopes`. The prototype pawl starts hidden;
the Blender floor and orange pawl reference solids are not displayed. Install
its isolated
environment once, then open this mechanical directory in VS Code and run the
file:

```sh
make setup-vscode
code alphabets-mechanical.code-workspace
```

Open the supplied workspace file rather than the repository root: it selects
the dedicated interpreter and the viewer's `browser` theme. It uses the same
optional `ALPHABETS_PROFILE` value as CQ-editor, so a selected profile changes
both views and generated fabrication files consistently.

The generated files are committed so a fabricator does not need CadQuery:

- `generated/cut/*.dxf`: millimetre cutter profiles;
- `generated/print/*.stl`: printable spool sides;
- `generated/step/*.step`: drum, card, motor, and reference assemblies;
- `generated/preview/*.svg`: shared mechanical review projections;
- `generated/manifest.json`: dimensions, source files, bounding boxes and
  validation status.
- `generated/captured-enclosure/`: the sole current enclosure source outputs:
  capture-fitted upper/lower and pawl STL/STEP files, the A1 Mini print plate,
  assembly STEP, review SVG, and a manifest tied to frame `27464`.

`make verify-generated` regenerates everything, executes the geometry tests
and fails if the committed outputs are stale.

## Fabrication boundary

The card and laser-cut drum reproduce the current repository dimensions. The
motor model is a nominal clearance envelope. Motor variation, material
thickness, kerf, shaft fit, sensor placement and the holder/enclosure references
still require measurement on the physical module before a production order.
STEP is the exchange format for downstream CAD; DXF is the cutting source and
STL is used only for additive parts.

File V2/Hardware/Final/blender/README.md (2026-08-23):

<!-- SPDX-FileCopyrightText: 2014-2026 The Beach Lab <https://beachlab.org> -->
<!-- SPDX-License-Identifier: MIT -->

# Blender gravity scene

This directory turns the definitive CadQuery geometry into a Blender rigid-body
review scene. CadQuery remains the fabrication source; Blender is used only to
settle the 64 cards under gravity, inspect stacking, and refine the enclosure.

Build and open the scene with:

```sh
cd V2/Hardware/Final/blender
make setup
make open
```

The generated scene contains one active rigid body and one hinge constraint per
card. Every front/back sticker is a separately named child object, but all 128
faces share one texture atlas. `generated/sticker-mapping.json` records the
character, card face, atlas coordinates, and required rotation.
Lower/front artwork is horizontally flipped in UV space so it reads correctly
after the flap turns into the lower display position.

The simulation deliberately models assembly in two phases:

- frames 1-194: southern cards start vertically downward and northern cards
  start 0.5 degrees away from perfectly upright, toward their falling direction.
  This deterministic imperfection gives gravity a non-zero starting torque.
  Cards are released in physical shingling order:
  rear-to-front through the south, then rear-to-front through the north;
- frames 195-800: the stack settles against the fixed pawl and the manually
  positioned floor.

The provisional CadQuery enclosure is deliberately not imported: this scene is
intended to discover the volume that the new enclosure must provide. The only
lower boundary is `CompressionFloor_Adjustable`, an auxiliary collision plane
that has no animation or keyframes. Move it manually on Z before running the
simulation. It is deliberately oversized and is not enclosure geometry. Walls
should be added only after the settled cards and the pawl define their required
envelope.

## Adjustable card-stop pawl

`CardStopPawl_Adjustable` is a stationary vertical plate, 1 mm thick, in its
own collection. It is not parented to the drum. Its inner face is flush with
the finished front face of vertical `card_01`. Its object origin is centered on
the lower inner support edge, whose Z position is halfway between the axes of
the `card_01` and `card_02` holes. Select it and use Blender's `G`/`R` controls
or the Item panel to refine the placement.

The pawl is part of the simulation because it is what keeps `card_01` vertical
after the card rigid bodies are released. It remains stationary while the drum
and cards move.

## Interactive floor and sticker preview

The generated interactive file is unbaked. `CompressionFloor_Adjustable` is a
passive collider with `Animated` enabled and no keyframes. Start timeline
playback, select the floor, and move it on Z: rigid-body collisions update as
new frames are evaluated. Blender does not solve physics while the timeline is
paused; after changing an already evaluated frame, return to frame 1 to clear
and replay the live cache.

After positioning the floor, save the blend file and persist its exact transform
with:

```sh
/Applications/Blender.app/Contents/MacOS/Blender \
  generated/alphabets-v2-interactive.blend --background \
  --python capture_floor.py
```

This writes `generated/floor-position.json`; subsequent generated scenes reuse
that transform automatically.

## Long-running enclosure capture

Run `make long-run` to build the interactive scene used for enclosure capture.
The floor is already stationary with its top 75 mm below the drum axis and its
front edge below the pawl; it is never swept through the cards. Play once to the
`READY_TO_ROTATE` marker at frame 360, then use the `Alphabets` sidebar to turn
the drum. The scene ends at frame 1,000,000 and playback is configured to stop,
not loop. A five-degree initial fall bias in the southern cards avoids the
perfectly vertical Bullet contact while the stack is being initialized.

The sticker atlas is packed into the blend file, and its 3D viewports are saved
in Material Preview. If a viewport is manually switched to Solid mode, press
`Z` and select `Material Preview` to see the artwork again.

Each generated `.blend` stores its MIT licence and The Beach Lab attribution in
the scene's custom properties and embeds the complete licence text in a text
block named `LICENSE`. Those records remain inside the document when the blend
file is shared on its own.

## Advance the drum for multiple revolutions

The installed `Alphabets Drum Step` add-on exposes an `Alphabets` tab in the 3D
View sidebar. Each step rotates the two drum disks, both structural supports,
the motor shaft, and all 64 hinge axes by exactly `-5.625` degrees around world
X: anticlockwise when viewed from the motor at negative X. `Steps per move` may
be used for several positions; the total step counter continues beyond 64.

Each position uses a 96-frame sinusoidal motor movement followed by 96 settling
frames. The button remains disabled until both phases finish. Cards remain
independent rigid bodies, hinged to a motor-driven kinematic drum body. The scene
uses 32 Bullet substeps per frame and 50 solver iterations. `Reset simulation`
returns to the blank position.

A deterministic 0.05 mm center-of-mass tolerance toward the falling side keeps
an upright card from returning to mathematically perfect equilibrium when it
loses the pawl. This is a simulation tolerance, not a change to card geometry.

After moving the pawl, save the blend file and capture the exact transform with:

```sh
/Applications/Blender.app/Contents/MacOS/Blender \
  generated/alphabets-v2-pawl-layout.blend --background \
  --python capture_pawl.py
```

This writes `generated/pawl-position.json`. The captured value is simulation
evidence only until it is reviewed and transferred into CadQuery dimensions.

## Capture the card envelope for the enclosure

After settling or stepping the cards to the position that must fit inside the
enclosure, save `generated/alphabets-v2-interactive.blend` and run:

```sh
make capture-envelope
```

This measures every evaluated card and sticker vertex at the saved frame and
writes `generated/card-envelope.json`, including the source blend hash, frame,
step position, drum radius, and upper/lower extrema. It is retained as an
independent measurement workflow alongside the captured-card enclosure scene.

## Static 5 × 2 HALLO / WELT! wall

Build the presentation scene with:

```sh
make hello-wall
```

The result is the technical scene
`generated/hello-wall/alphabets-hallo-welt-5x2.blend` plus a JSON manifest. No
render is generated. Its ten modules preserve the current CadQuery enclosure
dimensions and docking pitch. The top row reads `HALLO` and the lower row reads
`WELT!`, representing the spoken phrase `HALLO WELT!` without spending an
eleventh module on the space.

Every module contains both enclosure halves, both drum discs and both drum
supports, all 64 captured cards, all 128 sticker faces, the definitive pawl,
the complete motor reference, four M3 screws and six 3 × 1 mm magnets seated in
their CAD pockets. PCBs and cables remain excluded. Sticker backgrounds use a
low-roughness gloss-black material with yellow Blue Highway lettering from the
production atlas, so every displayed glyph shares its scale and baseline. At
captured display position 37, the requested full glyph is mapped continuously
across `sticker_38_back` above and `sticker_37_front` below.

The file also includes a front orthographic render camera and Blender's packed
`studio.exr` HDRI. The build prepares these resources but does not render an
image.

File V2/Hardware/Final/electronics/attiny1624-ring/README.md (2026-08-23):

<!-- SPDX-FileCopyrightText: 2014-2026 The Beach Lab <https://beachlab.org> -->
<!-- SPDX-License-Identifier: MIT -->
# Alphabets V2 ATtiny1624 ring module

This directory contains the editable KiCad 10 design for one Alphabets V2
split-flap module. The board keeps the existing 2x3 synchronous-ring connector,
drives an external four-input stepper board, reads a powered HOME sensor, and
uses the ATtiny1624's one-wire UPDI programming interface.

The hardware assignment follows Microchip's
[ATtiny1624/1626/1627 data sheet](https://ww1.microchip.com/downloads/en/DeviceDoc/ATtiny1624-26-27-DataSheet-DS40002234B.pdf).
Microchip documents PA0 as UPDI/RESET and PA1, PA2, and PA3 as SPI0 MOSI, MISO,
and SCK respectively. The standard programming connection is the 2x3,
2.54 mm UPDI header described in Microchip's
[UPDI connection guide](https://onlinedocs.microchip.com/oxy/GUID-ACE76F82-8072-410B-AFA7-16B2BF7B4CBA-en-US-8/GUID-C59C16EC-2784-4583-8198-2780FE485FFC.html).

## Circuit

- `U1`: ATtiny1624-SSU in SOIC-14.
- `J1`: 2x3 SMD ring connector for LATCH, CLOCK, serial data, +5 V, and GND.
- `J3`: four logic outputs for the external stepper driver.
- `J4`: powered three-pin HOME sensor connector with a 10 kOhm pull-up.
- `J5`: 2x3 SMD UPDI connector; pins 1, 2, and 6 carry UPDI, target VDD, and
  GND. Pins 3 through 5 are intentionally not connected.
- `R1`: 10 kOhm UPDI pull-up; `R2`: 10 kOhm HOME pull-up.
- `C1`: 100 nF local MCU decoupling; `C2`: 1 nF high-frequency bypass;
  `C3`: 10 uF board bulk capacitance.
- `JP1` through `JP4`, `JP6`, and `JP9`: removable 0 Ohm 1206
  links that partition power, ground, and ring signals for assembly and
  diagnosis.

The board defines this ATtiny1624 signal assignment:

| Function | MCU signal | Physical pin |
| --- | --- | ---: |
| VDD | `VDD` | 1 |
| LATCH | `PA4 / SPI0 SS` | 2 |
| HOME | `PA5` | 3 |
| Motor 4 | `PB3` | 6 |
| Motor 3 | `PB2` | 7 |
| Motor 2 | `PB1` | 8 |
| Motor 1 | `PB0` | 9 |
| UPDI | `PA0 / UPDI` | 10 |
| DATA_IN | `PA1 / SPI0 MOSI` | 11 |
| DATA_OUT | `PA2 / SPI0 MISO` | 12 |
| CLOCK | `PA3 / SPI0 SCK` | 13 |
| GND | `GND` | 14 |

`PA6` and `PA7` remain available and are intentionally not connected in this
revision. The matching firmware and host-side protocol tests are in
[`ATtiny1624 module firmware`](../../../../Firmware/attiny1624-module).

## Connectors

| Connector | Pinout |
| --- | --- |
| `J1 CHAIN` | 1 `LATCH`, 2 `CLOCK`, 3 `DATA_IN`, 4 `+5V`, 5 `DATA_OUT`, 6 `GND` |
| `J3 DRIVER` | 1 `MOTOR1`, 2 `MOTOR2`, 3 `MOTOR3`, 4 `MOTOR4` |
| `J4 HOME` | 1 `+5V`, 2 `HOME`, 3 `GND` |
| `J5 UPDI` | 1 `UPDI`, 2 target `VDD`, 3-5 NC, 6 `GND` |

The chain connector follows the [module protocol](../../../../Protocol/PROTOCOL.md):
pins 1, 2, 4, and 6 are bused, while pin 5 of one module feeds pin 3 of the
next module.

## Single-sided construction

- Finished outline: 50 x 50 mm.
- All routed copper is on `F.Cu`; the design contains no vias or back-copper
  tracks.
- Preferred tracks are 20 mil (0.508 mm). Constrained neckdowns are 16 mil
  (0.4064 mm), above the 15 mil minimum.
- Copper clearance is 0.40 mm for a 0.40 mm milling tool.
- Corners use native KiCad arcs with adaptive radii from 0.20 to 2.00 mm.
- Width transitions use curved copper tapers and routed SMD entries use curved
  teardrops.
- Every discrete resistor and capacitor uses a hand-solderable 1206 footprint.

Ten insulated wire links cross above the routed copper. Solder insulated wire
between the two pads of each footprint; the dashed `F.Fab` line marks its
assembly path and is not copper:

| Reference | Signal | Pad spacing |
| --- | --- | ---: |
| `JP5` | CLOCK | 22.3 mm |
| `JP7` | DATA_IN | 25.6 mm |
| `JP8` | DATA_OUT | 23.5 mm |
| `JP10` | UPDI | 16.6 mm |
| `JP11` | chain GND | 29.7 mm |
| `JP12` | motor phase 3 | 23.5 mm |
| `JP13` | MCU power source | 17.7 mm |
| `JP14` | motor phase 1 | 30.3 mm |
| `JP15` | motor phase 2 | 24.5 mm |
| `JP16` | main power distribution | 27.0 mm |

## Files and reproducible validation

- `attiny1624-ring.kicad_pro`, `.kicad_sch`, and `.kicad_pcb`: editable
  native KiCad project files.
- `fabrication/`: Gerbers, drill outputs, BOM, positions, and STEP model.
- `preview/`: top render, front-copper drawing, and schematic drawing.
- `validation/`: ERC and DRC/schematic-parity reports.
- `routing/attiny1624-ring.ses`: checked-in single-layer routing session.
- `tools/`: deterministic generators, route import, organic post-processing,
  and project-specific electrical/mechanical checks.

The normal reproducible path starts from the checked-in route:

```sh
make schematic board route organic check fabrication previews
```

Set `KICAD_CLI`, `KICAD_PYTHON`, `KIUTILS_PYTHON`, and
`KICAD10_FOOTPRINT_DIR` for the installed KiCad environment. When placement or
the netlist changes, create a new session with:

```sh
make autoroute FREEROUTING_JAR=/path/to/freerouting.jar
```

`make check` enforces the 50 x 50 mm outline, front-copper-only routing, zero
vias, 16/20 mil widths, ten wire links, native arcs, teardrops, zero ERC/DRC
violations, zero unrouted connections, and exact schematic-to-PCB parity.

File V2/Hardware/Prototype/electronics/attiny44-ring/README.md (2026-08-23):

<!-- SPDX-FileCopyrightText: 2014-2026 The Beach Lab <https://beachlab.org> -->
<!-- SPDX-License-Identifier: MIT -->
# Alphabets V2 ATtiny44 SPI-ring module

This directory contains the editable KiCad 10 design for one Alphabets V2
split-flap module. The ATtiny44 participates in the synchronous serial ring
defined in the [prototype module protocol](../../../../Protocol/PROTOCOL_V1_ATTINY44.md)
and drives the four
logic inputs of the external stepper-driver board supplied with the motor.
Its AVR C firmware is in
[`ATtiny44 module firmware`](../../../../Firmware/attiny44-module).

## Circuit

- `U1`: ATtiny44A-SS in SOIC-14.
- `J1`: one 2x3, 2.54 mm, surface-mount chain connector.
- `J5`: one standard 2x3, 2.54 mm, surface-mount AVR ISP connector placed
  immediately below `U1`.
- `J3`: four logic outputs for `IN1` through `IN4` on the external driver.
- `R2`: 10 kOhm reset pull-up in 1206.
- `C1`: 100 nF MCU decoupling capacitor in 1206.
- `C2`: 10 uF bulk capacitor in 1206.
- `JP5`, `JP6`, `JP7`, `JP8`, and `JP16` through `JP25`: 0 Ohm 1206 links
  used as physical copper bridges.

The ATtiny44 signal assignment follows the
[Microchip ATtiny24A/44A/84A data sheet](https://ww1.microchip.com/downloads/en/DeviceDoc/ATtiny24A-44A-84A-DataSheet-DS40002269A.pdf).

## Connectors

| Connector | Pinout |
| --- | --- |
| `J1 CHAIN` | 1 `LATCH`, 2 `CLOCK`, 3 `DATA_IN`, 4 `+5V`, 5 `DATA_OUT`, 6 `GND` |
| `J3 DRIVER` | 1 `IN1`, 2 `IN2`, 3 `IN3`, 4 `IN4` |
| `J5 ISP` | 1 `MISO`, 2 `+5V`, 3 `SCK`, 4 `MOSI`, 5 `RESET`, 6 `GND` |

The chain harness buses pins 1, 2, 4, and 6. It connects pin 5 of each module
to pin 3 of the following module. The external motor-driver board shares the
regulated 5 V supply and ground with this module.

`PB2/HOME` is unconnected on this PCB revision. The firmware uses an explicit
position-0 calibration command and persists completed positions in EEPROM.

## Milling rules

- Board outline: 50 x 50 mm.
- All routed copper is on `F.Cu`.
- Preferred tracks are 20 mil (0.508 mm); compact neckdowns remain 16 mil
  (0.4064 mm), never below the requested 15 mil minimum.
- Routed clearance is 0.40 mm for a 0.40 mm milling bit.
- Corners are native KiCad arcs fitted independently against DRC, trying radius
  limits from 2.00 mm down to 0.20 mm only where the 0.40 mm isolation requires
  it.
- Changes between 20 mil and 16 mil use curved 0.90 mm copper tapers; routed
  SMD pad entries use separate curved copper teardrops.
- Crossings use 0 Ohm 1206 links.
- All discrete SMD passives use 1206 footprints.
- `JP20` through `JP25` use the project-local compact-pitch 3216 crossover
  footprint so their pads fit between the adjacent milled traces.

## Files and validation

- `attiny44-ring.kicad_pro`, `.kicad_sch`, and `.kicad_pcb`: editable native
  KiCad project files.
- `fabrication/`: front-copper Gerbers, drill data, BOM, positions, and STEP.
- `preview/`: rendered top, copper, and schematic views.
- `validation/`: current ERC and DRC/schematic-parity reports.
- `tools/`: deterministic schematic, single-layer routing, organic post-process,
  and design checks.
- `third_party/`: the vendored, licensed geometry engines from
  [KiCad Round Tracks 1.6](https://github.com/mitxela/kicad-round-tracks/releases/tag/1.6)
  and [NilujePerchut's teardrop helper](https://github.com/NilujePerchut/kicad_scripts).

The workflow uses native files and command-line validation rather than GUI
automation. The checked-in Freerouting session reproduces the verified routing
deterministically. Set the KiCad paths, then run:

```sh
make schematic board route organic check fabrication previews
```

`make board route` is the easy-to-edit angular source. `make organic` creates
the fabrication board by fitting 20 mil tracks wherever DRC preserves the full
0.40 mm isolation, retaining 16 mil only where the compact layout requires it.
It then fits the largest safe radius at every corner, adds smooth width tapers
and curved SMD teardrops, and runs the normal ERC/DRC, fabrication, and preview
steps.

Use `make autoroute FREEROUTING_JAR=/path/to/freerouting.jar` only when the
placement or netlist changes and a new routing session must be explored.

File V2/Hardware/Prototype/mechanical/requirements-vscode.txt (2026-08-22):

# SPDX-FileCopyrightText: 2014-2026 The Beach Lab <https://beachlab.org>
# SPDX-License-Identifier: MIT
# Must track the installed OCP CAD Viewer VS Code extension (v4.x).
ocp-vscode~=4.0.1

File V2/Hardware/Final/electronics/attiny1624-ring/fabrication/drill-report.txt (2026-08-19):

Drill report for attiny1624-ring.kicad_pcb
Created on 2026-08-19T04:56:44

Copper Layer Stackup:
    =============================================================
    L1 :  F.Cu                      front
    L2 :  B.Cu                      back

Drill file 'attiny1624-ring-PTH.drl' contains
    plated through holes:
    =============================================================

    Total plated holes count 0

Drill file 'attiny1624-ring-NPTH.drl' contains
    unplated through holes:
    =============================================================

    Total unplated holes count 0

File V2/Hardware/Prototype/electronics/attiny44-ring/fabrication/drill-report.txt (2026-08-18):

Drill report for attiny44-ring.kicad_pcb
Created on 2026-08-18T14:54:11

Copper Layer Stackup:
    =============================================================
    L1 :  F.Cu                      front
    L2 :  B.Cu                      back

Drill file 'attiny44-ring-PTH.drl' contains
    plated through holes:
    =============================================================

    Total plated holes count 0

Drill file 'attiny44-ring-NPTH.drl' contains
    unplated through holes:
    =============================================================

    Total unplated holes count 0

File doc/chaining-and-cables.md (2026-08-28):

<!-- SPDX-FileCopyrightText: 2014-2026 The Beach Lab <https://beachlab.org> -->
<!-- SPDX-License-Identifier: MIT -->
# Chaining and cables

[← Motherboard](motherboard.md) · [Documentation index](README.md) · [Next: Protocol →](protocol.md)

The module boards form a synchronous serial ring. Four signals are shared by
every board, while the data signal passes through each module and returns to
the controller.

```mermaid
flowchart LR
    C[Controller DATA OUT] --> M1[Module 1]
    M1 --> M2[Module 2]
    M2 --> MN[Module N]
    MN --> R[Controller DATA IN]
    B[CLOCK + LATCH + 5 V + GND] --- M1
    B --- M2
    B --- MN
```

## Six chain signals

| Signal | Connection |
| --- | --- |
| `LATCH` | Shared frame boundary for every module |
| `CLOCK` | Shared serial clock for every module |
| `DATA_IN` | Data arriving from the previous board |
| `VCC` | Regulated 5 V module supply |
| `DATA_OUT` | Data regenerated for the next board |
| `GND` | Common electrical reference |

On the 2×3 connector, pins 1, 2, 4, and 6 are bused. Pin 5 (`DATA_OUT`) from
module *n* goes to pin 3 (`DATA_IN`) on module *n + 1*. The final module's
`DATA_OUT` returns to the controller.

## Power wiring for ten modules

The ten-module prototype uses a regulated 5 V supply sized for at least 3 A;
5 V at 4 A is recommended. Its shared `+5V` and `GND` conductors must carry the
2.0 A nominal simultaneous-motor peak documented in [Motors](motors.md), plus
the module electronics. There is no 12 V rail or buck converter in this power
path.

Use these copper conductor sizes:

| Path | Conductor size |
| --- | --- |
| Shared `+5V` and `GND` power pair | 0.75 mm² minimum recommended; use AWG 18 when buying AWG cable |
| Short power run carrying the full load, no more than 1 m one way | 0.5 mm² / AWG 20 minimum |
| `CLOCK`, `LATCH`, `DATA_IN`, and `DATA_OUT` | 0.14–0.25 mm² / AWG 26–24 |

At 5 V, voltage drop is the limiting factor before cable heating. Keep `+5V`
and `GND` together as a power pair, make the full-current feed short, and inject
power in parallel when a long row or connector chain would otherwise carry the
complete load through every small contact. Each connector and PCB power path
that carries the combined load must be rated for that current; cable gauge
alone does not make an underrated contact safe.

Before fixing the cable design, run all ten motors simultaneously and measure
the voltage between `+5V` and `GND` at the most distant motor driver. Also check
the supply lead, connectors, and PCB power paths for abnormal heating.

## Why it is a ring

The return path carries module status and lets the controller discover the
chain length without assigning an address to every board. Physical chain order
is module order; software's `cell_to_module` map can then translate that order
into straight, serpentine, or custom display layouts.

> [!CAUTION]
> The logical connector definition and ten-module cable allowance are
> documented, but the connector choice and maximum cable length still require
> physical validation. Validate power drop and signal quality on the intended
> display size.

See the exact timing and frame rules in the
[module protocol](../V2/Protocol/PROTOCOL.md).

[← Motherboard](motherboard.md) · [Documentation index](README.md) · [Next: Protocol →](protocol.md)

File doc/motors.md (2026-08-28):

<!-- SPDX-FileCopyrightText: 2014-2026 The Beach Lab <https://beachlab.org> -->
<!-- SPDX-License-Identifier: MIT -->
# Motors

[← Enclosure](enclosure.md) · [Documentation index](README.md) · [Next: Module board →](module-board.md)

Every character module has its own motor. That motor only turns forward: it
advances the drum until the requested one of 64 positions reaches the window.

28BYJ-48 motor clearance model

## Current target

The CAD clearance model and firmware defaults target a 5 V 28BYJ-48 geared
stepper motor with a four-input ULN2003-style driver. The module board sends
four low-power phase signals to the driver; it does **not** drive the motor
coils directly.

```mermaid
flowchart LR
    M[ATtiny1624 module board] -->|4 phase signals| D[Motor driver]
    D -->|coil current| S[28BYJ-48 motor]
    S --> G[64-position drum]
```

## Positioning

The firmware uses forward-only half steps. Its default is 4096 half steps per
drum revolution at 500 half steps per second. Those are starting values, not a
measurement of every motor. The firmware spreads the configured revolution
count across 64 positions so small fractions do not accumulate as a position
error.

The HOME sensor gives the module a known position 0. After a failed or
interrupted movement, the module must find HOME again before normal position
commands are accepted.

## Power budget for ten motors

The ten-module prototype uses one regulated 5 V supply. It does not use a
12 V motor rail or a buck converter. The supply powers the 5 V motor drivers
and module electronics directly; do not source the motor current from a
controller's USB or logic-power pin.

The reference 5 V 28BYJ-48 datasheet specifies 50 Ohm ±7% phase resistance at
25 °C. At 5 V, that is nominally 100 mA per energized phase. The firmware's
half-step sequence can energize two phases, so the design allowance is 200 mA
per moving motor and 2.0 A for ten motors moving simultaneously. At the
datasheet's minimum resistance, the corresponding motor-only peak is about
2.15 A.

Use a regulated 5 V, 3 A supply as the minimum design size. A regulated 5 V,
4 A supply is recommended to leave margin for module logic, HOME sensors,
motor variation, and cable voltage drop. The firmware releases all motor
phases when movement finishes, but the supply and wiring must still be sized
for the simultaneous-motion peak.

The calculation above applies to the referenced 5 V winding. Before connecting
a batch, confirm that every motor is labelled 5 V and measure the resistance
from the red common wire to each phase wire. Recalculate the current if the
measured winding differs materially from 50 Ohm.

Source: Kiatronics/Welten Holdings,
[28BYJ-48 – 5V Stepper Motor datasheet](https://www.osepp.com/downloads/pdf/stepd-01-data-sheet.pdf)
(rated voltage and phase resistance, accessed 2026-08-28).

## What must be checked on hardware

- the actual steps per complete drum revolution;
- motor direction and phase order;
- shaft and mounting-hole fit;
- torque with all 64 cards installed;
- reliable HOME detection;
- heat and power use during repeated movement;
- supply voltage at the most distant driver while all ten motors move.

See the [module firmware guide](module-firmware.md) for the configurable values
and the [mechanical source](../V2/Hardware/Final/mechanical/README.md) for the
motor clearance model.

[← Enclosure](enclosure.md) · [Documentation index](README.md) · [Next: Module board →](module-board.md)

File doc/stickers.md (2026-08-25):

<!-- SPDX-FileCopyrightText: 2014-2026 The Beach Lab <https://beachlab.org> -->
<!-- SPDX-License-Identifier: MIT -->
# Stickers

[← Cards](cards.md) · [Documentation index](README.md) · [Next: Drum →](drum.md)

Stickers give the cards their color and characters. Every character is split
across two neighbouring card faces. The centre cut must therefore remain in
the correct place and the cards must be loaded in the exact fabrication order.

International 64 black-and-white sticker sheet

## Demo 64 for V2 Prototype

Prototype print-and-cut sticker sheet

Prototype uses this exact 64-position order; the trailing position is one
ASCII space:

```text
ABCDEFGHIJKLMNOPQRSTUVWXYZ:.0123456789$€&@%×/·#=*+-±()<>,'°■£~©␠
```

`␠` denotes the final ASCII space. The current Prototype fabrication file is
[`cut-print/cutprint.svg`](../V2/Hardware/Prototype/stickers/cut-print/cutprint.svg).
It contains the printed artwork and cutter lines used for the ten sticker sets
printed in Dubai. One uncut sticker is 50 × 80 mm; the centre cut creates two
50 × 40 mm faces for the 55 × 43 mm card.

## International 64

V2 Final uses the `international-64` sequence. Position 0 is a blank so a
homed display begins empty.

```text
 ABCDEFGHIJKLMNOPQRSTUVWXYZÄÖÜẞÑÇÉÅÆØ0123456789.,:!?-/'&@%€$£+#°
```

The sequence is not just a list for the web interface: it is the physical
order of the cards around every drum. Software sends position numbers, so the
software sequence and installed cards must match exactly.

## Sheet geometry

- One uncut sticker is 45 × 91 mm.
- The centre cut creates two 45 × 45.5 mm faces.
- The colored background extends 2 mm beyond the outer cut lines; the finished
  sticker dimensions do not change.
- Each face is centred on a 50 × 48 mm card.
- The standard presets are black/white, black/yellow, yellow/black, and
  white/black.

The generator converts type into vector paths. This keeps the appearance
independent of the fonts installed on the printer's computer.

## Design files

- Read the [sticker generator guide](../V2/Hardware/Final/stickers/README.md).
- See the [character-set definitions](../V2/Hardware/Final/stickers/letters.md).
- Inspect the generated SVG, cutter SVG, JSON manifest, and PDF outputs in
  [`V2/Hardware/Final/stickers`](../V2/Hardware/Final/stickers/).
- Open the Prototype print-and-cut file in
  [`V2/Hardware/Prototype/stickers`](../V2/Hardware/Prototype/stickers/README.md).

> [!CAUTION]
> `demo-64` belongs to V2 Prototype. `international-64` belongs to V2 Final.
> Choosing a different preset in software does not change the physical drum.

[← Cards](cards.md) · [Documentation index](README.md) · [Next: Drum →](drum.md)

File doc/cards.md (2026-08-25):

<!-- SPDX-FileCopyrightText: 2014-2026 The Beach Lab <https://beachlab.org> -->
<!-- SPDX-License-Identifier: MIT -->
# Cards

[← Documentation index](README.md) · [Next: Stickers →](stickers.md)

Each character module contains 64 cards, also called flaps. A card has a front
and a back. When the drum turns, the cards fall one after another and the two
visible halves combine to show one character.

Cut outline of a V2 Final card

Prototype uses the ten existing sticker sets printed in Dubai. Final is the
target for new batches and provides the extra card and sticker height required
by the expanded DACH and Nordic character map. Every part in a variant row
below must stay with that variant.

## Two matched card sizes

| Variant | Card body | Including tabs | Sticker on each face | Drum inner width |
| --- | ---: | ---: | ---: | ---: |
| V2 Prototype | 55 × 43 × 0.5 mm | 63 × 43 mm | 50 × 40 × 0.1 mm | 56 mm |
| V2 Final | 50 × 48 × 0.5 mm | 58 × 48 mm | 45 × 45.5 × 0.1 mm | 51 mm |

Both cards are completely visible. The sticker reaches the hinge edge; the
opposite free-edge strip is left unstickered—3 mm on Prototype and 2.5 mm on
Final.

## V2 Final dimensions

| Part | Size |
| --- | ---: |
| Visible card body | 50 × 48 mm |
| Complete width including both tabs | 58 mm |
| Card material | 0.5 mm thick |
| Sticker on each face | 45 × 45.5 mm, 0.1 mm thick |
| Finished covered area | 0.7 mm thick |

The tabs at the top are the pivots. They sit in the drum holes and let the card
rotate. The 45 mm-wide sticker is centred on the 50 mm card, leaving 2.5 mm on
each side. Its edge beside the centre cut faces the tabs.

## Why the dimensions must stay together

The card, sticker, drum, and enclosure form one matched system. Changing the
card width also changes the drum spacing and the required enclosure clearance.
V2 Prototype uses 55 mm cards and is incompatible with the 50 mm V2 Final
system described here.

The [V2 Prototype CadQuery package](../V2/Hardware/Prototype/mechanical/README.md)
generates its 55 × 43 mm card and matched 56 mm drum as one physical profile.

## Design files

- The editable and generated card files are in
  [`V2/Hardware/Final/cards`](../V2/Hardware/Final/cards/README.md).
- The V2 Final CadQuery model is in
  [`V2/Hardware/Final/mechanical`](../V2/Hardware/Final/mechanical/README.md).
- The Prototype card, drum and enclosure are in
  [`V2/Hardware/Prototype/mechanical`](../V2/Hardware/Prototype/mechanical/README.md).
- The exact Prototype/Final match is recorded in
  [`V2/Hardware/variants`](../V2/Hardware/variants/README.md).

> [!CAUTION]
> Make a small fit sample before cutting 64 cards. Material thickness, cutter
> kerf, stickers, and tab clearance all affect whether a card falls freely.

[← Documentation index](README.md) · [Next: Stickers →](stickers.md)

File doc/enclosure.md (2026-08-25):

<!-- SPDX-FileCopyrightText: 2014-2026 The Beach Lab <https://beachlab.org> -->
<!-- SPDX-License-Identifier: MIT -->
# Enclosure

[← Drum](drum.md) · [Documentation index](README.md) · [Next: Motors →](motors.md)

The enclosure is the body around one drum. It keeps neighbouring modules
aligned, supports the motor and shaft, carries the electronics, and leaves the
front open so the character can be seen.

Current capture-fitted V2 Final enclosure

## Current V2 Final design

The enclosure is a two-part CadQuery model with an open front and rear. The
opening makes it possible to load cards, route wires, and service the mechanism.
The current model also includes:

- motor-side and shaft-side supports;
- space for the module electronics;
- alignment features for arranging modules in rows and columns;
- a separate front pawl;
- upper and lower printed parts.

The geometry is built around the saved settled card positions, not only around
the 85 mm drum circle. That extra moving envelope matters because cards extend
beyond the drum while they flip. This capture-fitted model is the enclosure
shown in the VS Code OCP viewer and is the only current enclosure source. The
latest physical print was confirmed from this version on 2026-08-23.

## Current V2 Prototype design

Current V2 Prototype enclosure

The Prototype is a one-piece CadQuery enclosure with an open front and rear. It
uses the 55 × 43 mm card, 56 / 60.3 mm drum widths, Demo‑64 sticker geometry
and a pawl with the 6 mm Prototype extension defined in `design.toml`.

The shell has no horizontal assembly seam, magnet pockets or internal alignment
keys. Both sides have full rounded-rectangle pockets, and external truncated
pyramids and matching sockets align complete modules vertically. The current A1
Mini plate contains the enclosure and Prototype pawl as two objects.

Card orientations come from the local settled-position capture. Card, sticker,
drum, pawl and enclosure geometry comes from the Prototype `design.toml` and is
rebuilt by the Prototype package. A complete Prototype print and physical fit
check are still required.

## Files

- The editable source, parameters, commands, and validation notes are in the
  [mechanical README](../V2/Hardware/Final/mechanical/README.md).
- Printable STL, neutral STEP, the review SVG, and their manifest are all under
  [`generated/captured-enclosure`](../V2/Hardware/Final/mechanical/generated/captured-enclosure/).
- The four-part A1 Mini print plate used by this pipeline is
  [`captured-enclosure-bambu-a1-mini-four-part-plate.stl`](../V2/Hardware/Final/mechanical/generated/captured-enclosure/print/captured-enclosure-bambu-a1-mini-four-part-plate.stl).
- Prototype source, parameters and validation boundary are in the
  [Prototype mechanical README](../V2/Hardware/Prototype/mechanical/README.md).
- The Prototype two-object A1 Mini plate is
  [`captured-enclosure-bambu-a1-mini-prototype-plate.stl`](../V2/Hardware/Prototype/mechanical/generated/captured-enclosure/print/captured-enclosure-bambu-a1-mini-prototype-plate.stl).

> [!WARNING]
> The complete V2 mechanism is not production-validated. Test one module with
> the correct variant's drum, cards, motor, shaft, pawl, alignment features and
> cables before printing an array. The Prototype enclosure still needs its
> first complete physical fit check.

[← Drum](drum.md) · [Documentation index](README.md) · [Next: Motors →](motors.md)

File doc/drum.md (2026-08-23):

<!-- SPDX-FileCopyrightText: 2014-2026 The Beach Lab <https://beachlab.org> -->
<!-- SPDX-License-Identifier: MIT -->
# Drum

[← Stickers](stickers.md) · [Documentation index](README.md) · [Next: Enclosure →](enclosure.md)

The drum is the rotating frame inside one character module. It holds all 64
cards in a fixed order. The motor turns the drum forward while the pawl lets
the cards fall one at a time.

V2 Final drum and card reference

## Main dimensions

| Property | V2 Final value |
| --- | ---: |
| Card positions | 64 |
| Drum diameter | 85 mm |
| Space between the inner faces | 51 mm |
| Complete outside width | 55.3 mm |
| Card-pivot circle radius | 40 mm |

The 51 mm inside space is the 50 mm card body plus 1 mm total side clearance.
Two 2.15 mm drum sides make the complete drum 55.3 mm wide.

## How one position is selected

```mermaid
flowchart LR
    A[Module receives position 0-63] --> B[Motor turns forward]
    B --> C[Cards pass the pawl]
    C --> D[Requested card pair is visible]
    D --> E[Motor stops and releases]
```

The controller never sends a character to a module. It sends a number from 0
to 63. The installed card order decides which character that number shows.

## Design files

- Editable drum geometry is in the
  [CadQuery mechanical model](../V2/Hardware/Final/mechanical/README.md).
- STEP, STL, DXF, SVG, and a machine-readable manifest are in
  [`V2/Hardware/Final/mechanical/generated`](../V2/Hardware/Final/mechanical/generated/).
- The full dimensional match is in the
  [physical variants contract](../V2/Hardware/variants/README.md).

> [!CAUTION]
> Generated geometry is not proof of a working mechanism. Check card fall,
> motor direction, shaft fit, pawl position, and clearances on one module.

[← Stickers](stickers.md) · [Documentation index](README.md) · [Next: Enclosure →](enclosure.md)

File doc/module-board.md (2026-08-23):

<!-- SPDX-FileCopyrightText: 2014-2026 The Beach Lab <https://beachlab.org> -->
<!-- SPDX-License-Identifier: MIT -->
# Module board

[← Motors](motors.md) · [Documentation index](README.md) · [Next: Motherboard →](motherboard.md)

Each character has an identical module board. The board receives one command
from the chain, controls one motor, reads one HOME sensor, and sends its status
back through the ring.

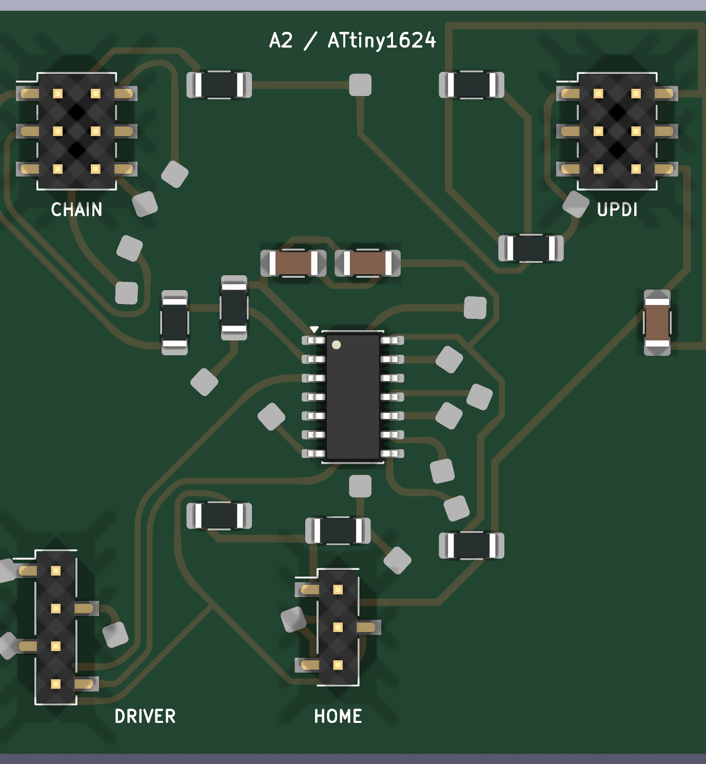
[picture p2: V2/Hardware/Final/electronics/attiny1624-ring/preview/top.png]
Top render of the ATtiny1624 module board


## Main parts

| Part | Purpose |
| --- | --- |
| ATtiny1624 | Runs the module firmware |
| Chain connector | LATCH, CLOCK, DATA IN, DATA OUT, 5 V, and ground |
| Motor-driver connector | Four phase-control signals |
| HOME connector | 5 V, sensor signal, and ground |
| UPDI connector | Programs and debugs the microcontroller |

The current board is 50 × 50 mm and routes all PCB copper on one side. It uses
insulated wire links where signals must cross. That construction choice is
intended to make the board practical to mill and hand assemble.

## Signal path

```mermaid
flowchart LR
    IN[DATA IN] --> MCU[ATtiny1624]
    MCU --> OUT[DATA OUT]
    HOME[HOME sensor] --> MCU
    MCU --> DRIVER[External motor driver]
    UPDI[UPDI programmer] --> MCU
```

## Design and fabrication files

The [board README](../V2/Hardware/Final/electronics/attiny1624-ring/README.md)
explains the circuit, connector pinouts, single-sided routing, and validation
commands. The same directory contains editable KiCad files, fabrication
exports, previews, and saved ERC/DRC reports.

> [!CAUTION]
> Passing electrical-rule and design-rule checks does not replace assembly and
> electrical testing on a real board.

[← Motors](motors.md) · [Documentation index](README.md) · [Next: Motherboard →](motherboard.md)

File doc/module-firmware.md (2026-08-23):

<!-- SPDX-FileCopyrightText: 2014-2026 The Beach Lab <https://beachlab.org> -->
<!-- SPDX-License-Identifier: MIT -->
# Module embedded software

[← Protocol](protocol.md) · [Documentation index](README.md) · [Next: Motherboard firmware →](motherboard-firmware.md)

The same firmware runs on every V2 Final module. A board does not know which
letter it controls or where it appears in a wall. Its place in the cable chain
determines its physical index.

```mermaid
stateDiagram-v2
    [*] --> LoadSavedPosition
    LoadSavedPosition --> Ready: saved position is valid
    LoadSavedPosition --> NeedsHome: no valid position
    NeedsHome --> Homing: command 0x41
    Homing --> Ready: HOME edge found
    Ready --> Moving: new position command
    Moving --> Ready: target reached and saved
    Moving --> NeedsHome: power interrupted
```

## What it does

- receives and forwards bytes through the SPI ring;
- reports present, ready, and current position;
- finds position 0 with the active-low HOME sensor;
- turns the motor forward without blocking communication;
- saves completed positions in a wear-levelled EEPROM journal;
- marks the position unknown before movement, so interrupted motion cannot be
  reported as successful;
- releases the motor phases and sleeps when idle.

## Source and checks

The implementation is in
[`V2/Firmware/attiny1624-module`](../V2/Firmware/attiny1624-module/README.md).
Portable host tests exercise the protocol and movement state machine. AVR GCC
builds the firmware image for the ATtiny1624.

The repository also preserves
[`V2/Firmware/attiny44-module`](../V2/Firmware/attiny44-module/README.md) for
the incompatible Prototype board.

> [!CAUTION]
> Host tests and a successful firmware build do not prove correct motor,
> sensor, timing, or ring behavior on assembled hardware.

[← Protocol](protocol.md) · [Documentation index](README.md) · [Next: Motherboard firmware →](motherboard-firmware.md)

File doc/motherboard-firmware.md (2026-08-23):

<!-- SPDX-FileCopyrightText: 2014-2026 The Beach Lab <https://beachlab.org> -->
<!-- SPDX-License-Identifier: MIT -->
# Motherboard embedded software

[← Module firmware](module-firmware.md) · [Documentation index](README.md) · [Next: Web interface →](web-interface.md)

The motherboard firmware will be the translator between human-readable text
and the physical module ring.

```mermaid
flowchart TD
    A[Receive JSON message] --> B[Validate text and layout]
    B --> C[Build the complete character grid]
    C --> D[Map characters to drum positions]
    D --> E[Map logical cells to cable order]
    E --> F[Send module frames]
    F --> G{All modules ready?}
    G -->|No| F
    G -->|Yes| H[Report display.ready]
```

## Required behavior

The protocol contract already defines the important rules:

- persistent rows, columns, character set, module protocol, and wiring map;
- automatic chain discovery and topology checking;
- deterministic wrapping and alignment;
- explicit errors instead of silent character replacement or truncation;
- conversion from logical cells to physical module order;
- automatic homing and motion-timeout handling;
- one active display update at a time.

## Current status

> [!IMPORTANT]
> Motherboard firmware is not present in the repository yet. The
> [message protocol](../V2/Protocol/MESSAGE_PROTOCOL.md),
> [module protocol](../V2/Protocol/PROTOCOL.md), character-set files, and JSON
> Schema are an implementation contract, not evidence of a running controller.

The firmware should be tested first with simulated modules, then with one real
module, and only then with a longer chain. This separates text/layout bugs from
electrical and mechanical problems.

[← Module firmware](module-firmware.md) · [Documentation index](README.md) · [Next: Web interface →](web-interface.md)

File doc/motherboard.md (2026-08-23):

<!-- SPDX-FileCopyrightText: 2014-2026 The Beach Lab <https://beachlab.org> -->
<!-- SPDX-License-Identifier: MIT -->
# Motherboard

[← Module board](module-board.md) · [Documentation index](README.md) · [Next: Chaining and cables →](chaining-and-cables.md)

The motherboard is the central controller for the complete display. It sits
between applications and the chain of character modules.

```mermaid
flowchart LR
    WEB[Web interface or other app] -->|UTF-8 JSON| MB[Motherboard controller]
    MB -->|position commands| M1[Module 1]
    M1 --> M2[Module 2]
    M2 --> MN[Module N]
    MN -->|status return| MB
```

## Responsibilities

The existing protocol documents define what the controller must do:

- store the display's rows, columns, wiring map, character set, and protocol version;
- discover how many modules are connected;
- turn text into a complete grid of characters;
- convert each character into its physical drum position;
- send commands in the correct chain order;
- wait until every module reports the requested position;
- report clear errors for bad text, wiring faults, or motion timeouts.

## Current status

> [!IMPORTANT]
> A motherboard schematic, PCB, and bill of materials are not present in the
> repository yet. This page describes the controller role defined by the
> [message protocol](../V2/Protocol/MESSAGE_PROTOCOL.md) and
> [module protocol](../V2/Protocol/PROTOCOL.md), not finished hardware.

The eventual hardware needs at least an application connection, the six chain
signals, regulated module power, and enough memory and processing capacity to
lay out a complete display message. Those implementation choices remain open.

[← Module board](module-board.md) · [Documentation index](README.md) · [Next: Chaining and cables →](chaining-and-cables.md)

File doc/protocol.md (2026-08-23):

<!-- SPDX-FileCopyrightText: 2014-2026 The Beach Lab <https://beachlab.org> -->
<!-- SPDX-License-Identifier: MIT -->
# Protocol

[← Chaining and cables](chaining-and-cables.md) · [Documentation index](README.md) · [Next: Module firmware →](module-firmware.md)

Alphabets uses two communication layers. The application layer talks in text;
the module layer talks in physical drum positions.

```mermaid
flowchart LR
    A[Application] -->|Message protocol: text and layout| C[Controller]
    C -->|Module protocol: positions 0-63| M[Module chain]
    M -->|Ready and current position| C
    C -->|Accepted, ready, or error| A
```

## 1. Message protocol

Applications send newline-delimited UTF-8 JSON. A `display.show` request can
contain text plus wrapping and alignment preferences. The controller knows the
real number of rows and columns and refuses text that cannot fit or cannot be
shown by the installed character set.

The controller first replies that a valid update was accepted. When every
module reaches its target, it reports that the display is ready.

Read the complete [message protocol](../V2/Protocol/MESSAGE_PROTOCOL.md) and
its [JSON Schema](../V2/Protocol/message_protocol.schema.json).

## 2. Module protocol

The controller opens a frame with `LATCH`, shifts one byte per module using a
shared clock, and closes the frame. Commands `0x01` through `0x40` mean drum
positions 0 through 63. `0x41` starts automatic homing on V2 Final modules.

Each status byte says whether a module is present, whether it is ready, and
which position it currently shows. Commands travel in reverse physical order
because every module forwards the byte it receives to the next module.

Read the complete [ATtiny1624 module protocol](../V2/Protocol/PROTOCOL.md).
The older [ATtiny44 protocol](../V2/Protocol/PROTOCOL_V1_ATTINY44.md) is kept
for V2 Prototype hardware.

[← Chaining and cables](chaining-and-cables.md) · [Documentation index](README.md) · [Next: Module firmware →](module-firmware.md)

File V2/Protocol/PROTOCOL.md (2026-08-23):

<!-- SPDX-FileCopyrightText: 2014-2026 The Beach Lab <https://beachlab.org> -->
<!-- SPDX-License-Identifier: MIT -->
# Alphabets V2 ATtiny1624 module protocol

Text applications communicate with the controller through the higher-level
[`MESSAGE_PROTOCOL.md`](MESSAGE_PROTOCOL.md). This document defines revision 2
of the link between that controller and the autonomous character modules.

## Purpose

The protocol controls a physical chain of autonomous split-flap modules. Every
module contains an ATtiny1624, a four-channel unipolar stepper driver, a home
sensor, and one 64-position drum. Physical chain order is display order, and
every module runs the same firmware image.

The ATtiny44 prototype protocol remains documented in
[`PROTOCOL_V1_ATTINY44.md`](PROTOCOL_V1_ATTINY44.md).

## Physical topology

The controller and modules form a synchronous serial ring:

```text
Controller DATA_OUT -> module 1 -> module 2 -> ... -> module N -> Controller DATA_IN

Controller CLOCK  --------------------------------------> every module
Controller LATCH  --------------------------------------> every module
```

Each module exposes one 2x3 chain connector:

| Pin | Signal | Function |
| --- | --- | --- |
| 1 | `LATCH` | Shared active-low frame boundary and SPI client select |
| 2 | `CLOCK` | Shared SPI clock |
| 3 | `DATA_IN` | Serial input from the previous physical position |
| 4 | `VCC` | Regulated 5 V module supply |
| 5 | `DATA_OUT` | Regenerated serial output to the next physical position |
| 6 | `GND` | Common reference |

The harness buses pins 1, 2, 4, and 6. It connects pin 5 of module `n` to pin
3 of module `n + 1`; the final module's pin 5 returns to the controller.

## ATtiny1624 signal assignment

The production target is an ATtiny1624-SSU in the 14-pin SOIC package. The SPI
assignment uses the peripheral's default route from the
[Microchip ATtiny1624 data sheet](https://onlinedocs.microchip.com/oxy/GUID-7056F141-DF07-46C5-A4B8-97EB46E9B945-en-US-12/GUID-FB911F82-41CD-40A2-82BE-947A57ED38FB.html).

| Signal | ATtiny1624 pin |
| --- | --- |
| `DATA_IN` | `PA1 / SPI0 MOSI`, physical pin 11 |
| `DATA_OUT` | `PA2 / SPI0 MISO`, physical pin 12 |
| `CLOCK` | `PA3 / SPI0 SCK`, physical pin 13 |
| `LATCH` | `PA4 / SPI0 SS`, physical pin 2 |
| `HOME` | `PA5`, physical pin 3, active low |
| Motor phase 1 | `PB0`, physical pin 9 |
| Motor phase 2 | `PB1`, physical pin 8 |
| Motor phase 3 | `PB2`, physical pin 7 |
| Motor phase 4 | `PB3`, physical pin 6 |
| Programming/debug | `PA0 / UPDI`, physical pin 10 |
| Supply | `VDD` pin 1 and `GND` pin 14 |

`HOME` uses the ATtiny1624 internal pull-up. The sensor closes to ground at the
position-0 reference. `PA0/UPDI` is reserved for programming and debug.

## Serial format and timing

`SPI0` operates in
[client normal mode](https://onlinedocs.microchip.com/oxy/GUID-7056F141-DF07-46C5-A4B8-97EB46E9B945-en-US-12/GUID-3423A0A4-55CA-43AD-AE91-0082B72CC9A8.html):

- SPI mode 0: clock idle low, sample on rising edges.
- Most-significant bit first.
- Eight bits per byte.
- Nominal and maximum `CLOCK` frequency: 50 kHz.
- At least 20 microseconds with `CLOCK` low between consecutive bytes.
- `LATCH` idles high and acts as the active-low client-select signal.

The controller waits at least 100 microseconds after lowering `LATCH` before
the first rising clock edge. It leaves at least 20 microseconds after the final
rising clock edge before raising `LATCH`. A valid frame contains only complete
bytes.

## Frame lifecycle

A complete frame follows this sequence:

1. The controller drives `LATCH` low.
2. Every module loads its current status byte into `SPI0.DATA`.
3. The controller waits at least 100 microseconds.
4. The controller shifts one byte per module while reading the return stream.
5. Each module forwards every fully received byte during the next byte time.
6. The controller waits at least 20 microseconds and drives `LATCH` high.
7. Every module applies the final complete byte it received as its command.

This byte pipeline lets discovery continue until the controller receives its
marker without assigning addresses or fixing the chain length.

Commands are transmitted in reverse physical order. For a four-module display
whose target positions are `H O L A`, the controller transmits the command for
`A`, then `L`, then `O`, and finally `H`.

Status bytes return in reverse physical order during the same transfer. The
first returned byte belongs to the final module in the chain.

## Protocol revision selection

The controller stores one module-protocol profile for the installed chain:
`attiny1624-v2` for this protocol or `attiny44-v1` for the prototype protocol.
This keeps the shared position commands and six-wire harness while selecting
the correct `0x41` homing behavior for every module in the chain.

## Command byte

Every command byte has bit 7 cleared.

| Value | Command |
| --- | --- |
| `0x00` | Keep the current target |
| `0x01` to `0x40` | Move to drum position 0 to 63 (`position = value - 1`) |
| `0x41` | Run the automatic position-0 homing cycle |

The home cycle always searches in the normal forward direction. If `HOME` is
already active, the module first advances until the sensor releases and then
uses the next active edge, confirmed across two consecutive motor steps, as
position 0. The search is limited to two drum revolutions. A successful cycle
records position 0; an expired search stops and leaves the module unreferenced.

Drum position identifiers follow the character set selected in the controller
settings. Canonical presets and custom-profile validation are defined in
[`../Hardware/Final/stickers/character_sets.json`](../Hardware/Final/stickers/character_sets.json)
and documented in
[`../Hardware/Final/stickers/letters.md`](../Hardware/Final/stickers/letters.md).

Modules are character-set agnostic: they receive only position identifiers.
The selected 64-character software sequence must match the physical flap order
installed on every connected module.

## Status byte

Every status byte has bit 7 set.

```text
bit 7      module present marker, always 1
bit 6      ready
bits 5..0  current drum position, 0 to 63
```

`ready` is cleared while the position reference is unknown, during homing or
normal movement, and while a completed position is being persisted. It is set
after the requested position is reached, the motor phases are released, and
the current position is stored.

The controller completes a display update when every module reports `ready = 1`
and its current position matches the requested position. A module that remains
unready after the motion deadline is reported as a fault at its physical
display position. The controller may retry `0x41` for an unreferenced module.

## Automatic chain discovery

The controller discovers the chain at startup and after a topology change:

1. Drive `LATCH` low.
2. Transmit `0x00` bytes and read the return stream.
3. Count every returned byte whose bit 7 is set.
4. Stop when the first transmitted `0x00` returns with bit 7 cleared.
5. Wait at least 20 microseconds, drive `LATCH` high, and store the count.

The number of status bytes before the returned marker is the chain length.
Their order runs from the final module back to the first, so the controller
reverses it for applications. A scan accepts up to 255 modules and reports a
return-path fault when the marker misses the scan deadline.
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

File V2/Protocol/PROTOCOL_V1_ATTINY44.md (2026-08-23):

<!-- SPDX-FileCopyrightText: 2014-2026 The Beach Lab <https://beachlab.org> -->
<!-- SPDX-License-Identifier: MIT -->
# Alphabets V2 module protocol

Text applications communicate with the controller through the higher-level
[`MESSAGE_PROTOCOL.md`](MESSAGE_PROTOCOL.md). This document defines the link
between that controller and the autonomous character modules.

## Purpose

The Alphabets V2 protocol controls a physical chain of autonomous split-flap
modules. Each module contains an ATtiny44, an external unipolar stepper-driver
board, and one 64-position drum.
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

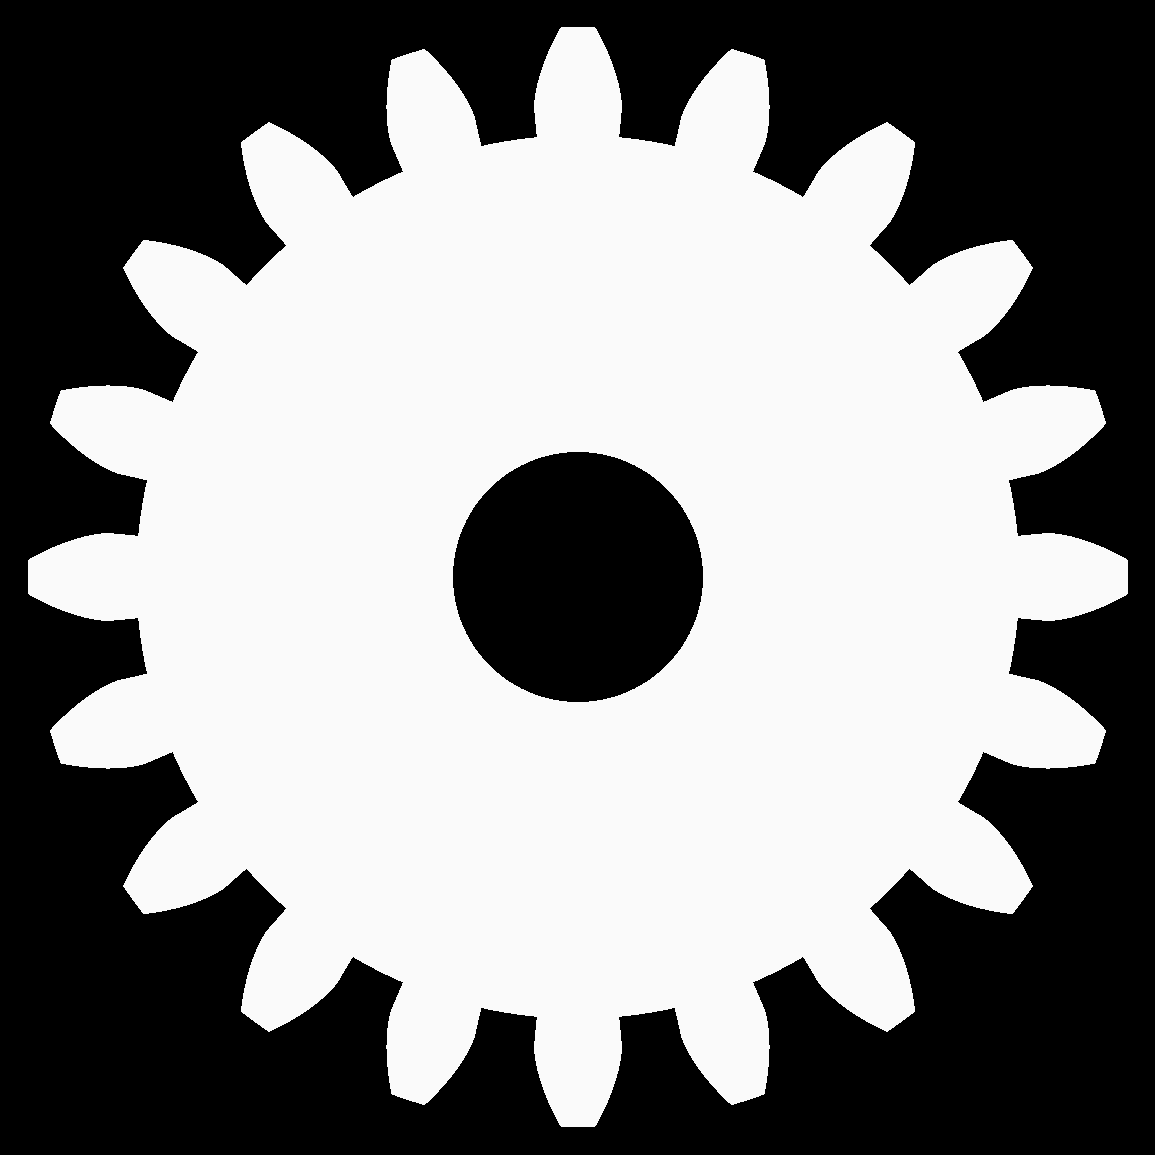
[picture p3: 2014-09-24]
mechanical/spool/.png

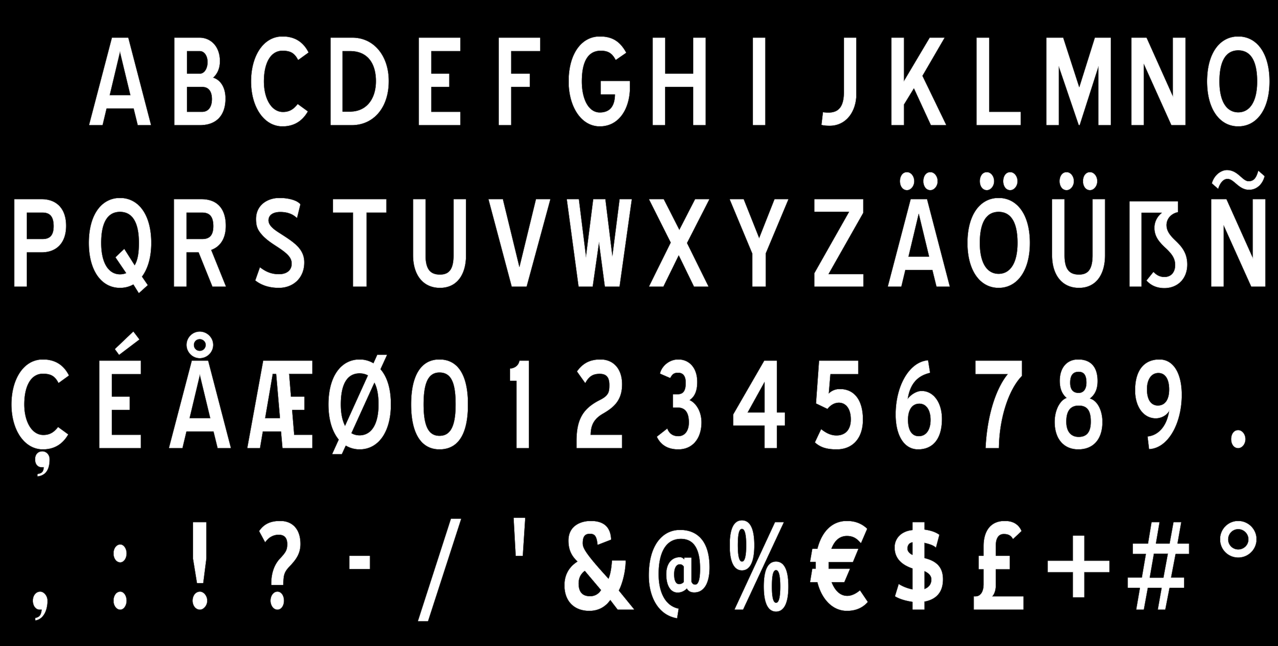
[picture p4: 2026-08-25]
V2/Hardware/Final/blender/generated/sticker-atlas.png

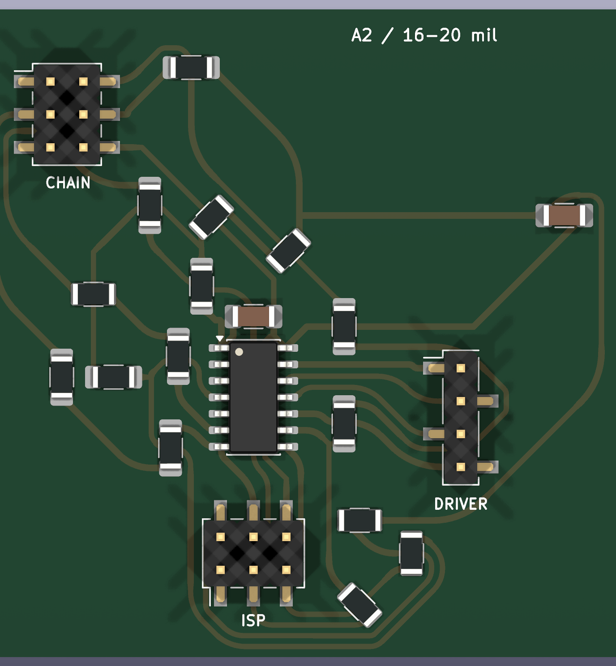
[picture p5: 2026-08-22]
V2/Hardware/Prototype/electronics/attiny44-ring/preview/top.png

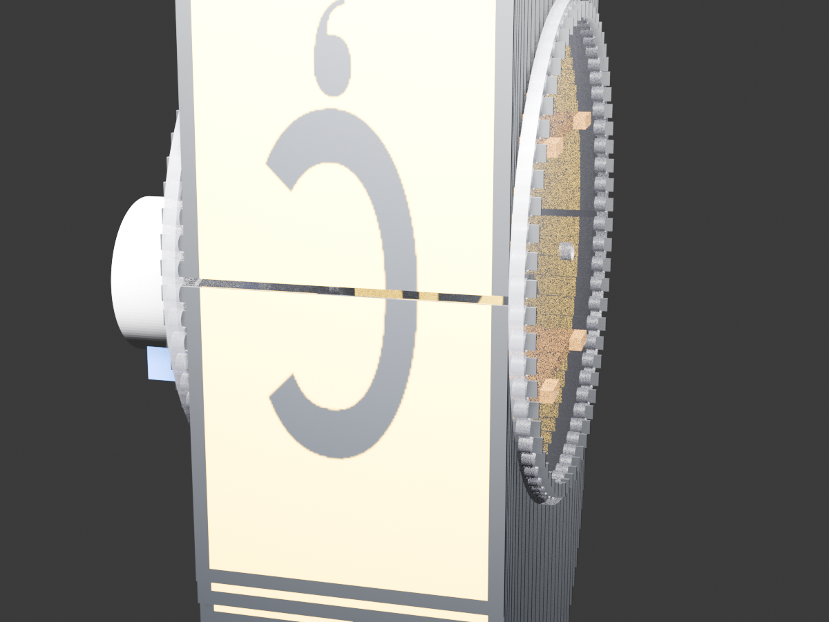
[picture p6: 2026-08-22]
V2/Hardware/Final/blender/generated/alphabets-v2-interactive.png

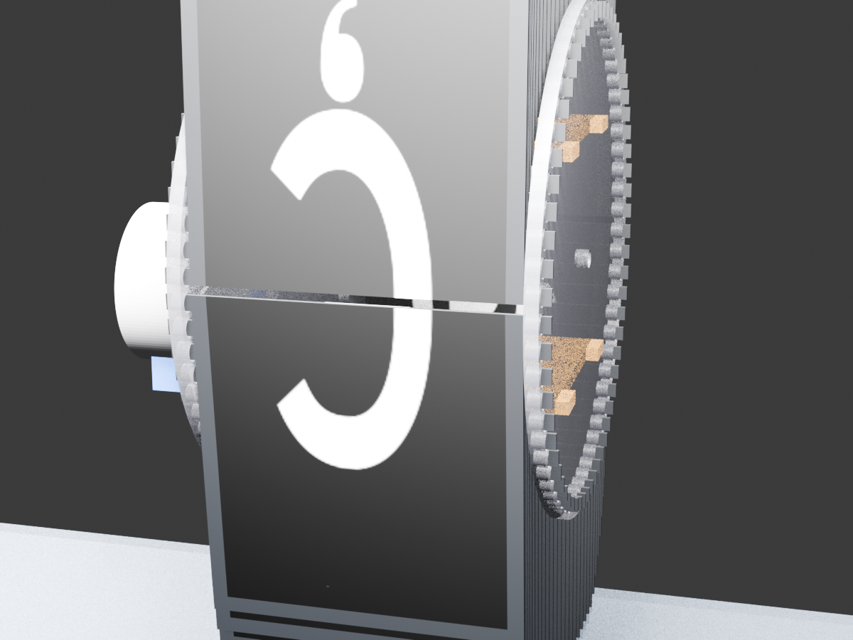
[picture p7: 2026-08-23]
V2/Hardware/Final/blender/generated/alphabets-v2-long-run.png

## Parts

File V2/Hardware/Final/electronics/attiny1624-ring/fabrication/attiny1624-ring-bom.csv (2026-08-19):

Refs | Value | Footprint | Qty
C1 | 100n MCU 1206 | Capacitor_SMD:C_1206_3216Metric_Pad1.33x1.80mm_HandSolder | 1
C2 | 1n HF 1206 | Capacitor_SMD:C_1206_3216Metric_Pad1.33x1.80mm_HandSolder | 1
C3 | 10u BULK 1206 | Capacitor_SMD:C_1206_3216Metric_Pad1.33x1.80mm_HandSolder | 1
J1 | CHAIN_RING | Connector_PinHeader_2.54mm:PinHeader_2x03_P2.54mm_Vertical_SMD | 1
J3 | STEPPER_DRIVER_IN | Connector_PinHeader_2.54mm:PinHeader_1x04_P2.54mm_Vertical_SMD_Pin1Left | 1
J4 | HOME_SENSOR | Connector_PinHeader_2.54mm:PinHeader_1x03_P2.54mm_Vertical_SMD_Pin1Left | 1
J5 | UPDI_2X3 | Connector_PinHeader_2.54mm:PinHeader_2x03_P2.54mm_Vertical_SMD | 1
JP1 | 0R CHAIN power bridge 1206 | Resistor_SMD:R_1206_3216Metric_Pad1.30x1.75mm_HandSolder | 1
JP2 | 0R UPDI power bridge 1206 | Resistor_SMD:R_1206_3216Metric_Pad1.30x1.75mm_HandSolder | 1
JP3 | 0R HOME power bridge 1206 | Resistor_SMD:R_1206_3216Metric_Pad1.30x1.75mm_HandSolder | 1
JP4 | 0R MCU power bridge 1206 | Resistor_SMD:R_1206_3216Metric_Pad1.30x1.75mm_HandSolder | 1
JP5 | INSULATED CLOCK LINK 22.3mm | Alphabets:WireLink_22.3mm_SMD | 1
JP6 | 0R LATCH bridge 1206 | Resistor_SMD:R_1206_3216Metric_Pad1.30x1.75mm_HandSolder | 1
JP7 | INSULATED DATA_IN LINK 25.6mm | Alphabets:WireLink_25.6mm_SMD | 1
JP8 | INSULATED DATA_OUT LINK 23.5mm | Alphabets:WireLink_23.5mm_SMD | 1
JP9 | 0R MCU ground bridge 1206 | Resistor_SMD:R_1206_3216Metric_Pad1.30x1.75mm_HandSolder | 1
JP10 | INSULATED UPDI LINK 16.6mm | Alphabets:WireLink_16.6mm_SMD | 1
JP11 | INSULATED GND LINK 29.7mm | Alphabets:WireLink_29.7mm_SMD | 1
JP12 | INSULATED MOTOR3 LINK 23.5mm | Alphabets:WireLink_23.5mm_SMD | 1
JP13 | INSULATED MCU POWER LINK 17.7mm | Alphabets:WireLink_17.7mm_SMD | 1
JP14 | INSULATED MOTOR1 LINK 30.3mm | Alphabets:WireLink_30.3mm_SMD | 1
JP15 | INSULATED MOTOR2 LINK 24.5mm | Alphabets:WireLink_24.5mm_SMD | 1
JP16 | INSULATED MAIN POWER LINK 27.0mm | Alphabets:WireLink_27.0mm_SMD | 1
R1 | 10k UPDI pull-up 1206 | Resistor_SMD:R_1206_3216Metric_Pad1.30x1.75mm_HandSolder | 1
R2 | 10k HOME pull-up 1206 | Resistor_SMD:R_1206_3216Metric_Pad1.30x1.75mm_HandSolder | 1
U1 | ATtiny1624-SSU | Package_SO:SOIC-14_3.9x8.7mm_P1.27mm | 1

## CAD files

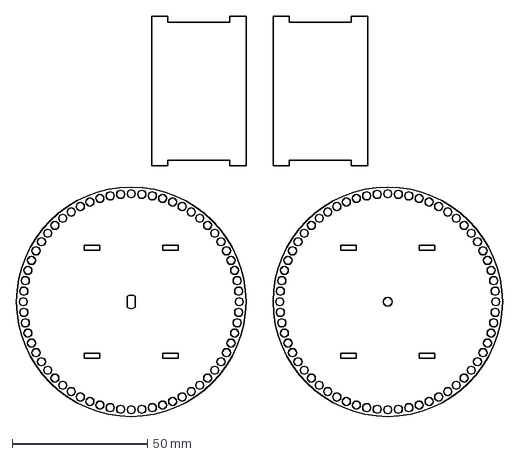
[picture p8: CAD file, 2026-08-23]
V2/Hardware/Final/mechanical/generated/cut/drum-complete-layout.dxf
180.0 x 148.2 mm

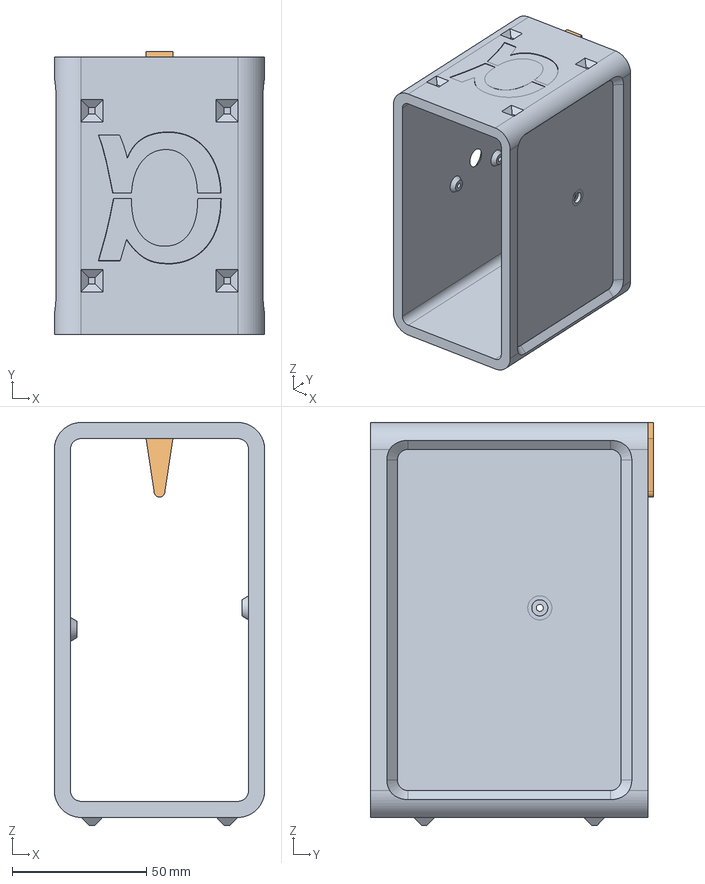
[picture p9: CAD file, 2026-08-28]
V2/Hardware/Prototype/mechanical/generated/captured-enclosure/step/captured-enclosure-assembly.step
78.3 x 105.3 x 150.0 mm

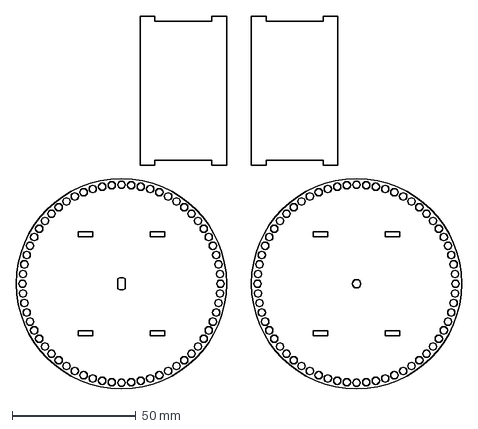
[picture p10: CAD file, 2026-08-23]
V2/Hardware/Prototype/mechanical/generated/cut/drum-complete-layout.dxf
180.0 x 150.7 mm

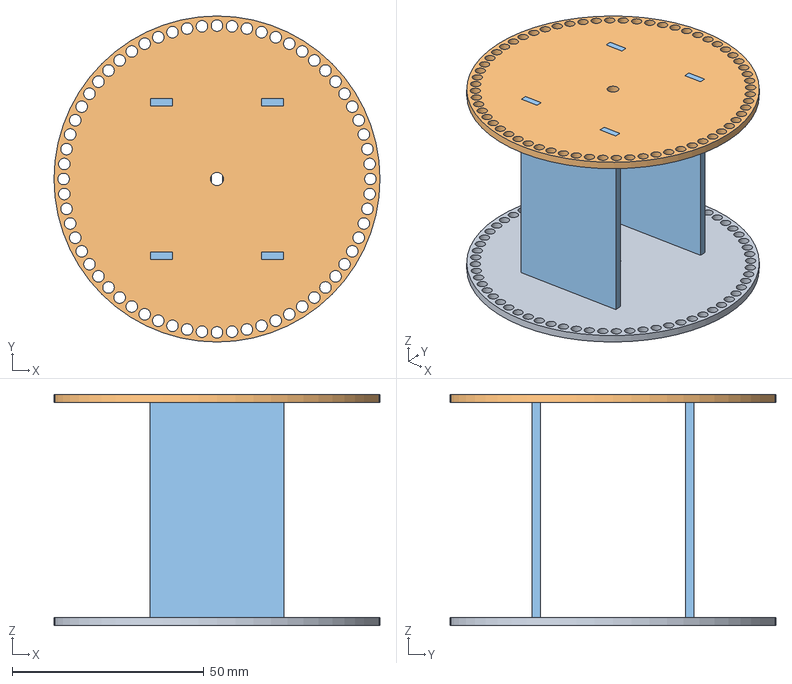
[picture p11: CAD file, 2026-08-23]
V2/Hardware/Prototype/mechanical/generated/step/drum-assembly.step
85.0 x 85.0 x 60.3 mm

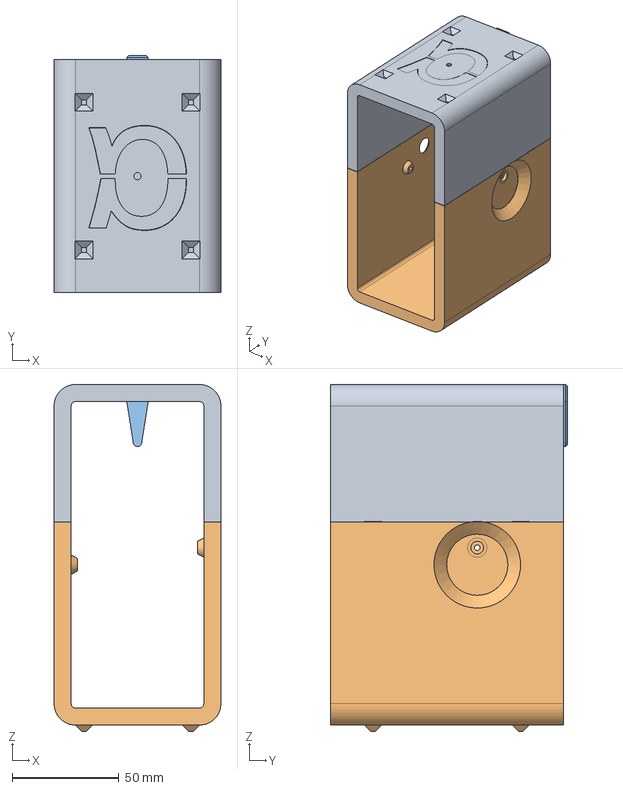
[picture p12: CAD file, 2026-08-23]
V2/Hardware/Final/mechanical/generated/captured-enclosure/step/captured-enclosure-assembly.step
78.0 x 111.1 x 162.3 mm

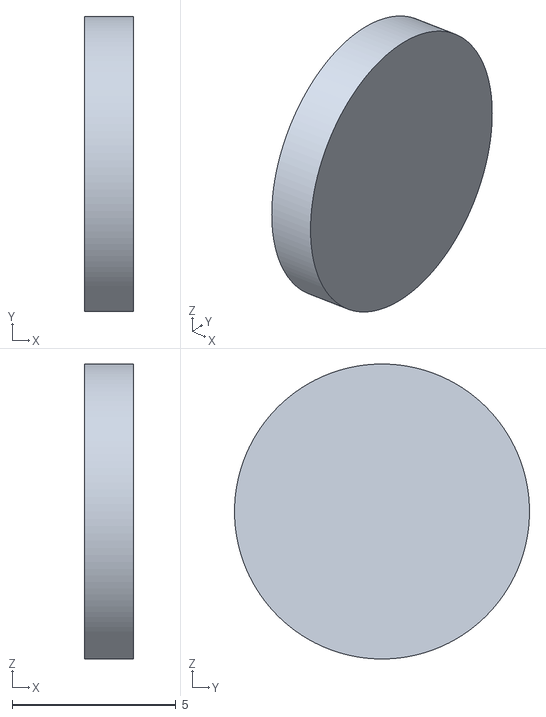
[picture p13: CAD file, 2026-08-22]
V2/Hardware/Final/blender/generated/meshes/motor_collar.stl
1.50 x 9.00 x 9.00

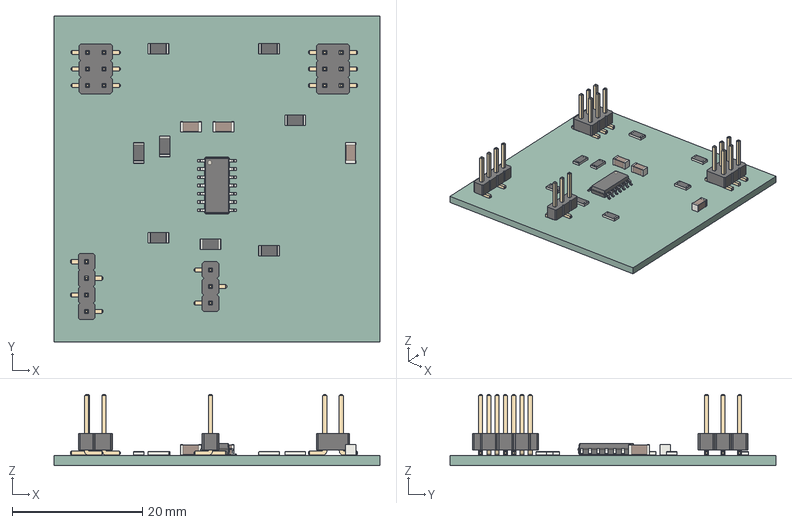
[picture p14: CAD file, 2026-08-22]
V2/Hardware/Final/electronics/attiny1624-ring/fabrication/attiny1624-ring.step
50.0 x 50.0 x 10.9 mm
SOIC-14_3.9x8.7mm_P1.27mm
R_1206_3216Metric x 8
PinHeader_1x04_P254mm_Vertical_SMD_Pin1Left
PinHeader_2x03_P254mm_Vertical_SMD x 2
C_1206_3216Metric x 3
PinHeader_1x03_P254mm_Vertical_SMD_Pin1Left
attiny1624-ring_PCB

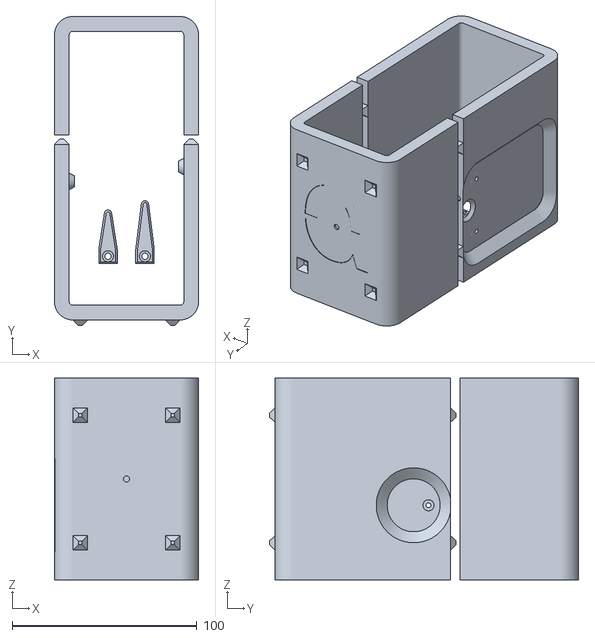
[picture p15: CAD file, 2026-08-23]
V2/Hardware/Final/mechanical/generated/captured-enclosure/print/captured-enclosure-bambu-a1-mini-four-part-plate.stl
78.0 x 167.2 x 109.1

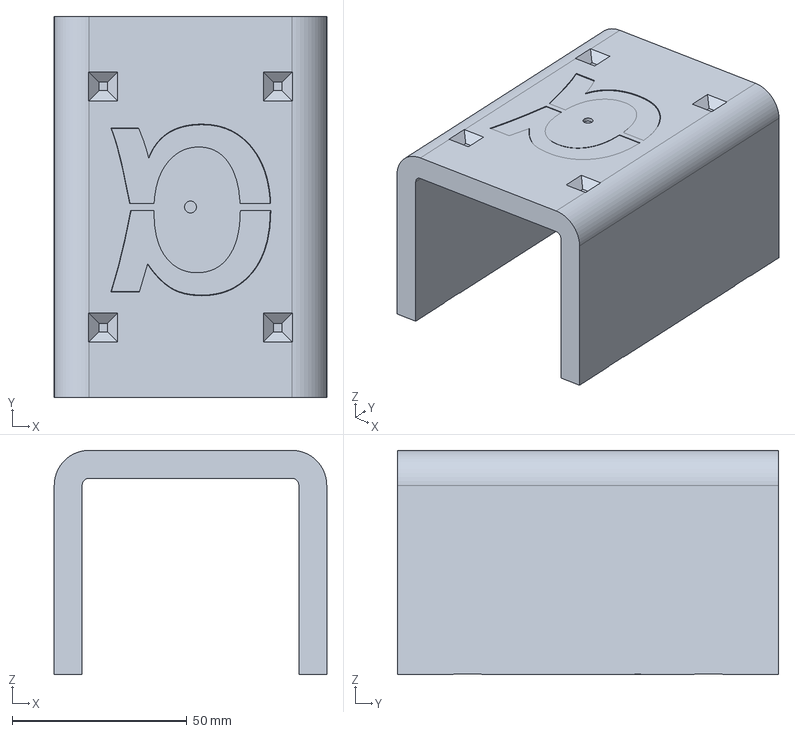
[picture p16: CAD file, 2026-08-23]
V2/Hardware/Final/mechanical/generated/captured-enclosure/step/captured-enclosure-upper.step
78.0 x 109.1 x 64.2 mm

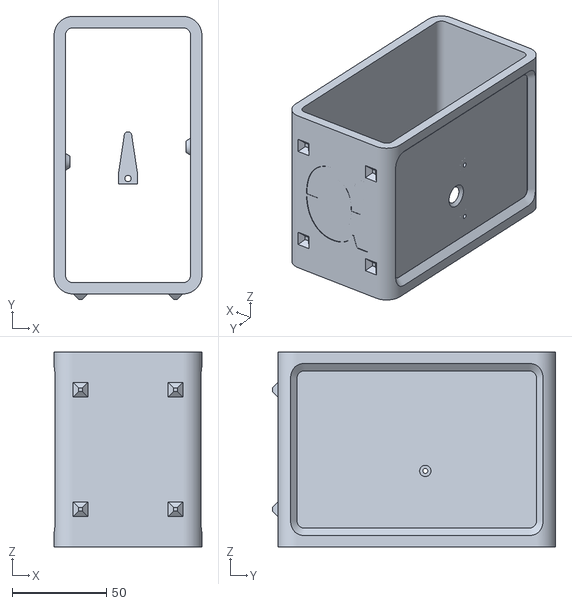
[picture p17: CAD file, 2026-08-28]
V2/Hardware/Prototype/mechanical/generated/captured-enclosure/print/captured-enclosure-bambu-a1-mini-prototype-plate.stl
78.3 x 150.0 x 103.3

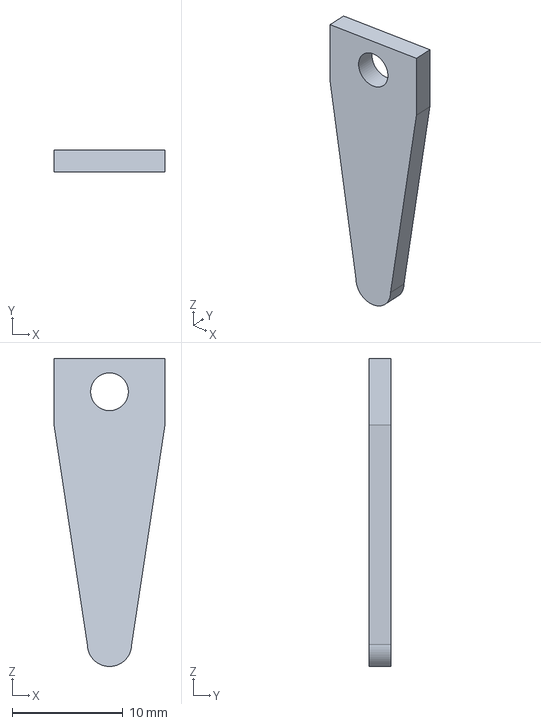
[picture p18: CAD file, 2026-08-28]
V2/Hardware/Prototype/mechanical/generated/captured-enclosure/step/captured-enclosure-pawl-prototype.step
10.0 x 2.00 x 27.8 mm

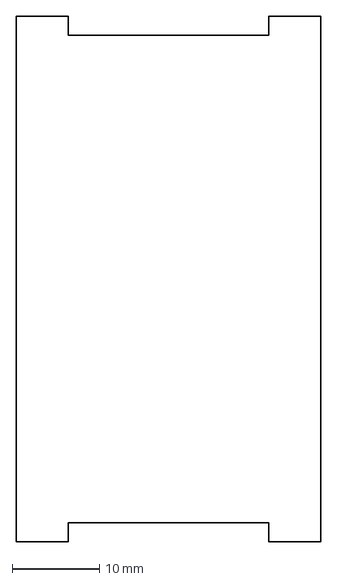
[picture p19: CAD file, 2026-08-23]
V2/Hardware/Prototype/mechanical/generated/cut/drum-support.dxf
35.0 x 60.3 mm

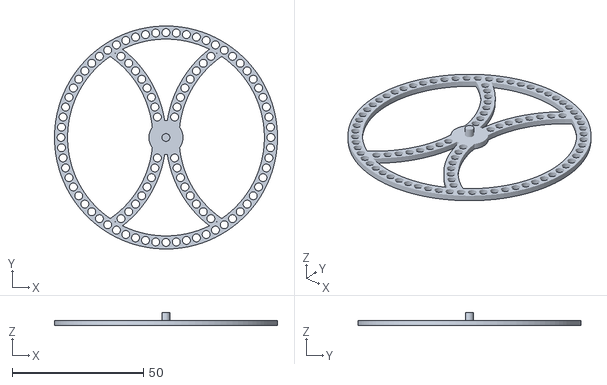
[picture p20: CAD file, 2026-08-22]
V2/Hardware/Prototype/mechanical/generated/print/spool-shaft-side.stl
85.0 x 85.0 x 5.00

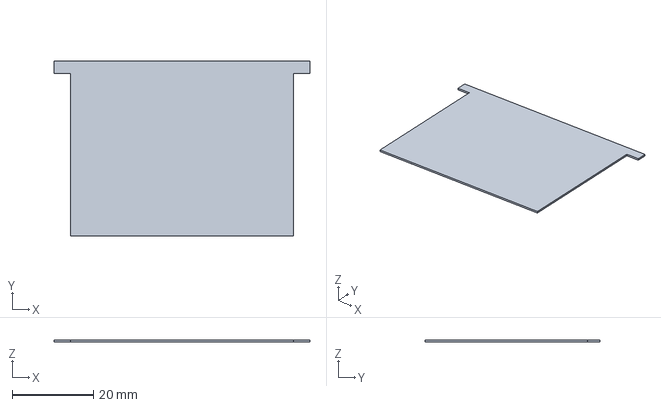
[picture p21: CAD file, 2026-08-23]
V2/Hardware/Prototype/mechanical/generated/step/flap-card.step
63.0 x 43.0 x 0.5 mm

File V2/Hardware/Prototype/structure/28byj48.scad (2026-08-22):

// SPDX-FileCopyrightText: 2015-2016 Scott Bezek and the splitflap contributors
// SPDX-License-Identifier: Apache-2.0
/*
   Copyright 2015-2016 Scott Bezek and the splitflap contributors

   Licensed under the Apache License, Version 2.0 (the "License");
   you may not use this file except in compliance with the License.
   You may obtain a copy of the License at

       http://www.apache.org/licenses/LICENSE-2.0

   Unless required by applicable law or agreed to in writing, software
   distributed under the License is distributed on an "AS IS" BASIS,
   WITHOUT WARRANTIES OR CONDITIONS OF ANY KIND, either express or implied.
   See the License for the specific language governing permissions and
   limitations under the License.
*/

// Basic 28BYJ-48 model based on various dimensioned drawings.
// Origin is centered on the shaft, on the front face of the motor, with the shaft in the +z direction
module Stepper28BYJ48() {
    $fn = 60;

    eps = 0.01;
    chassis_radius = 28/2;
    chassis_height = 19;
    shaft_offset = 8;
    mount_outer_radius = 3.5;
    mount_hole_radius = 4.2/2;
    mount_center_offset = 35/2;
    mount_bracket_height = 0.8;

    shaft_collar_radius = 9/2;
    shaft_collar_height = 1.5;

    shaft_radius = 5/2;
    shaft_height = 10;
    shaft_slotted_width = 3;
    shaft_slotted_height = 6;

    backpack_width = 14.6;
    backpack_extent = 18; // seen values from 17-18
    backpack_height = 16;

    gray = [0.7, 0.7, 0.7];
    gold = [1, 0.843, 0];
    blue = [0, 0, 1];

    module mounting_holes() {
        linear_extrude(height=mount_bracket_height) {
        difference() {
            hull() {
                translate([mount_center_offset, 0]) {
                    circle(r=mount_outer_radius);
                }
                translate([-mount_center_offset, 0]) {
                    circle(r=mount_outer_radius);
                }
            }

            translate([mount_center_offset, 0]) {
                circle(r=mount_hole_radius);
            }
            translate([-mount_center_offset, 0]) {
                circle(r=mount_hole_radius);
            }
        }
        }
    }

    module shaft_collar() {
        cylinder(r=shaft_collar_radius, h=shaft_collar_height + eps);
    }

    module shaft() {
        color(gold) {
            difference() {
                cylinder(r=shaft_radius, h=shaft_height);
                translate([-(shaft_radius + eps), shaft_slotted_width / 2, shaft_height - shaft_slotted_height]) {
                    cube([(shaft_radius+eps)*2, shaft_radius, shaft_slotted_height+eps]);
                }
                translate([-(shaft_radius + eps), - shaft_radius - (shaft_slotted_width / 2), shaft_height - shaft_slotted_height]) {
                    cube([(shaft_radius+eps)*2, shaft_radius, shaft_slotted_height+eps]);
                }
            }
        }
    }

    module chassis() {
        color(gray) {
            translate([0, 0, -chassis_height]) {
                cylinder(r=chassis_radius, h=chassis_height);
            }
            translate([0, 0, -mount_bracket_height]) {
                mounting_holes();
            }
            translate([0, shaft_offset, -eps]) {
                shaft_collar();
            }
        }
    }

    module backpack() {
        color(blue) {
            translate([-backpack_width/2, 0, -backpack_height - eps]) {
                cube([backpack_width, backpack_extent, backpack_height]);
            }
        }
    }

    translate([0, -shaft_offset, 0]) {
        chassis();
        translate([0, shaft_offset, 0]) {
            shaft();
        }
        translate([0, -backpack_extent, 0]) {
            backpack();
        }
    }
}

Stepper28BYJ48();

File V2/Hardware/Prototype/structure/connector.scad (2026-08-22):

// SPDX-FileCopyrightText: 2014-2026 The Beach Lab <https://beachlab.org>
// SPDX-License-Identifier: MIT

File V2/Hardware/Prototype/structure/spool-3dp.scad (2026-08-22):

// SPDX-FileCopyrightText: 2014-2026 The Beach Lab <https://beachlab.org>
// SPDX-License-Identifier: MIT
// Alphabets New Spool
$fn=(50);

// Parameters
ncards=64; // number of cards
sdiam=85; // diameter of the spool mm
e=2; // 3d printed part thickness mm

// Variables
srad=sdiam/2;
angle=360/ncards; // angle of rotation

// define copy_mirror function
module copy_mirror(vec=[0,1,0])
{
    children();
    mirror(vec) children();
} 

// Define axis motor
module axismotor() {
intersection() {square(size = [3, 6], center = true); circle(2.5);}
}

// Define axis support
module axis() {
circle(1.5);
}

// define aro
module aro() {
difference(){
    difference() { circle(srad); circle(srad-5);}
    for (a=[0:angle:360]){
    rotate(a) 
    translate([srad-2.5,0,0]) circle(1.5);
    }
}
}

// CODE STARTS HERE

linear_extrude(height = e) {
union(){    
aro();
    difference() {
        intersection() {
            union() {
                translate ([srad,0,0]) aro();
                translate ([-srad,0,0])  aro();
                circle (6.5);
                }
            circle(srad-5);
        }

    axismotor();
    }
}    
}

translate ([sdiam+5,0,0])
        union() {
        linear_extrude(height = 5) {circle(1.5);}
        linear_extrude(height = e) {
        union(){    
        aro();
                intersection() {
                    union() {
                        translate ([srad,0,0]) aro();
                        translate ([-srad,0,0])  aro();
                        circle (6.5);
                        }
                    circle(srad-5);
                }

        }    
        }
    }

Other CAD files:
V2/Hardware/Final/cards/card-50x48-cut.dxf
V2/Hardware/Prototype/electronics/attiny44-ring/fabrication/attiny44-ring.step
V2/Hardware/Prototype/structure/spool.dxf
V2/Hardware/Final/blender/generated/meshes/motor_side.stl
V2/Hardware/Prototype/structure/spool-holder.scad
V2/Hardware/Final/blender/generated/alphabets-v2-interactive.blend
V2/Hardware/Final/blender/generated/alphabets-v2-pawl-layout-flat-pawl-v2.blend
V2/Hardware/Final/blender/generated/meshes/motor_backpack.stl
V2/Hardware/Final/blender/generated/meshes/motor_body.stl
V2/Hardware/Final/blender/generated/meshes/motor_shaft.stl
V2/Hardware/Final/blender/generated/meshes/shaft_side.stl
V2/Hardware/Final/blender/generated/meshes/support_back.stl
V2/Hardware/Final/blender/generated/meshes/support_front.stl
V2/Hardware/Final/cards/card-50x48.fcstd
V2/Hardware/Final/cards/card-cut.dxf
V2/Hardware/Final/cards/card.fcstd
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

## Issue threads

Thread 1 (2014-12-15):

Plastic panel thickness

2lostkiwis, 2014-12-15:
Not sure if this is the right place, but I am trying to figure out how thick the plastic should be for the panels for the enclosure. My current guess is 5mm but it would be great if you could confirm this for me. Many thanks.

Fablabsitges, 2015-05-25:
Sorry about the delay, the thickness is 3 mm if you are using the V1 design files. But we are currently working in a second iteration of foldable cardboard.

Closed 2015-05-25.

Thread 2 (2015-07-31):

CAD Files are incompatible with new Kokopelli

hlieberman, 2015-07-31:
The CAD files for the circuit boards no longer work with newer versions of kokopelli.  There are several errors, some which are easy to resolve, and some which are harder.

Fablabsitges, 2015-08-30:
I know. I am pushing the former kokopelli in a new repository and I get back to you

hlieberman, 2015-10-05:
Hello!

I just wanted to check in to see if you were able to upload a copy of
kokopelli 0.05 anywhere.

Sincerely,

-- Harlan Lieberman-Berg
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

TheBeachLab, 2015-10-05:
I uploaded it to electronics folder. I wrote the instructions. Let me know how it goes

Closed 2015-10-05.

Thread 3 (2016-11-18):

Kokopelli issue

mrbbp, 2016-11-18:
Great project except kokopelli does not work on OSX10.11 el capitan (impossible to install wxpython and there for to compile sources...too). therefore we have a great project and useless file in obsolete file format. :(
no hardware usable too :(
If you want open source.
why don't you've used svg for gears as for the card?
and why no standart file format for pcb (fritzing is cool)... all your work become effortless and lost for community. It's sad.

and there is no picture too, a bit complexe to understand how to build.
please take some time to update project with usable file.

regards

éric

TheBeachLab, 2016-11-18:
The idea is porting the project to openscad and freecad for mechanical and
kicad for electronics. And upload the pics also. They got lost when I
killed wordpress.

Regarding that problem you have with kokopelli. If you haven't taken the
fab academy class I recommend you to step back. Even if you manage to
install it you will spend quite a lot of time trying to learn the basics
and using it. I love it but most people hate it. And you seem one of the
last.

Also have a look at the forks. Maybe someone has been already doing what
you are looking for.

Fran

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

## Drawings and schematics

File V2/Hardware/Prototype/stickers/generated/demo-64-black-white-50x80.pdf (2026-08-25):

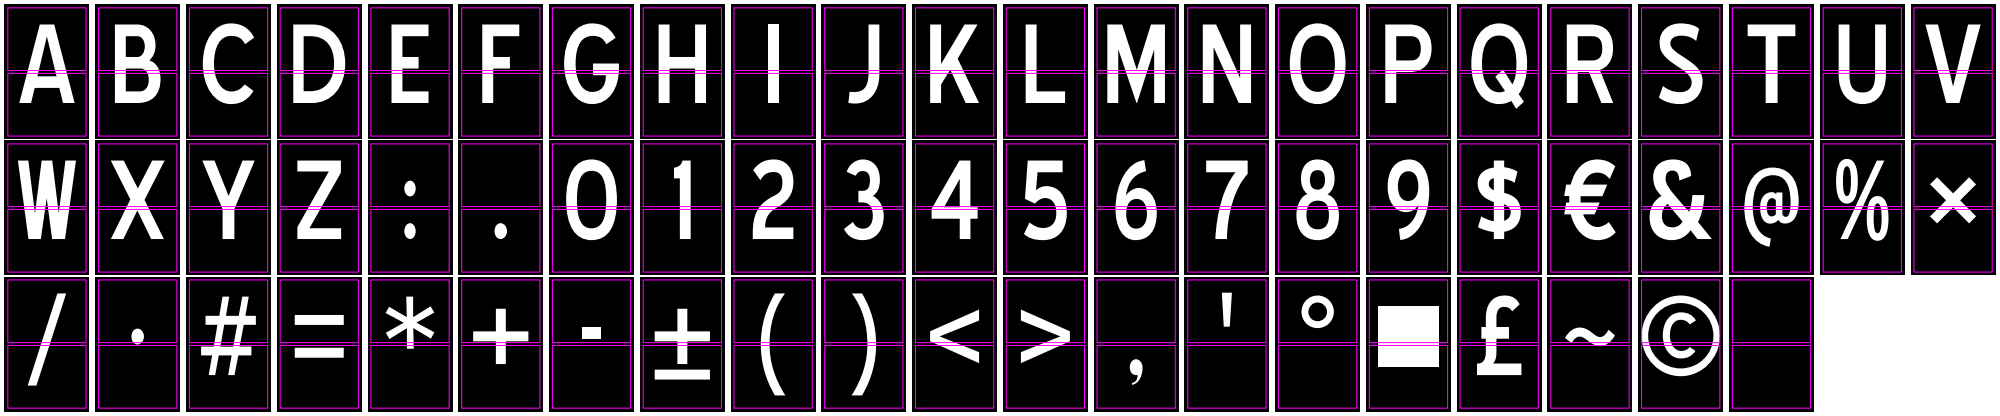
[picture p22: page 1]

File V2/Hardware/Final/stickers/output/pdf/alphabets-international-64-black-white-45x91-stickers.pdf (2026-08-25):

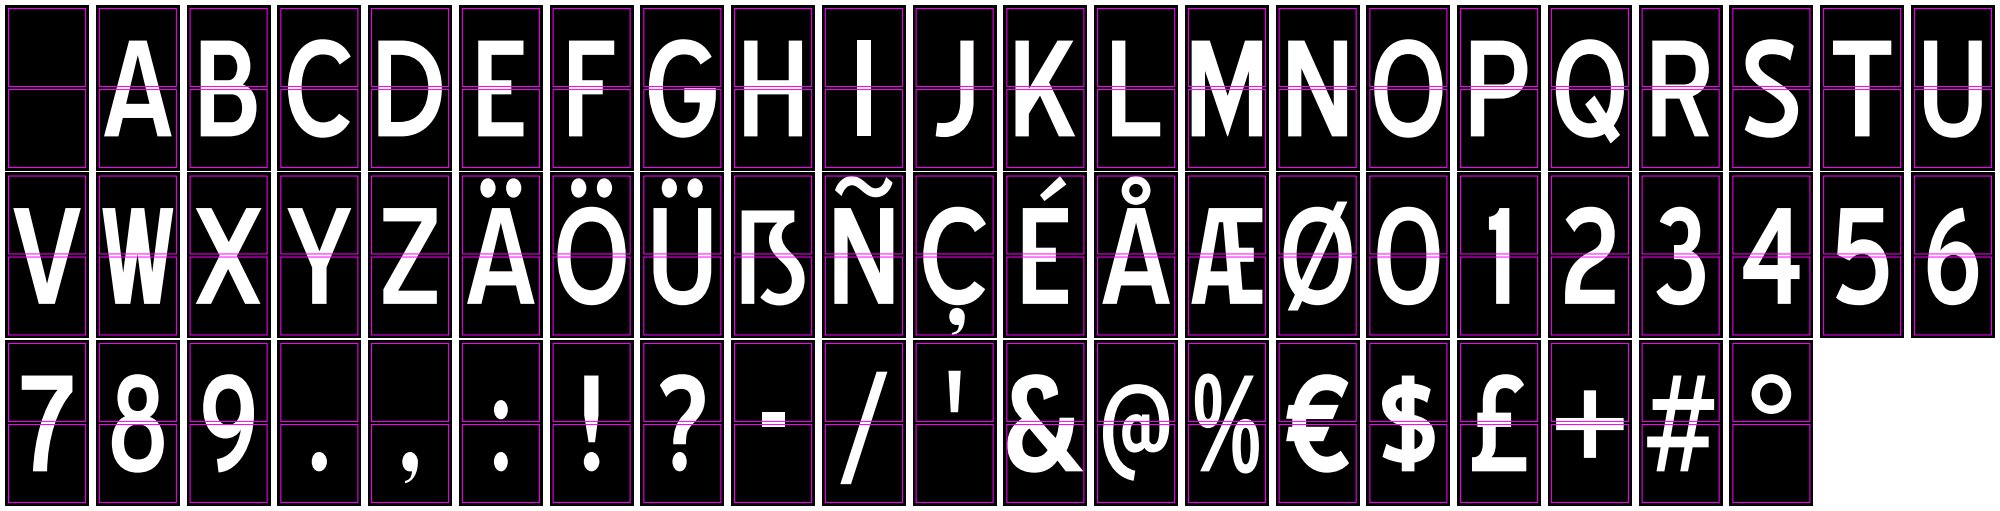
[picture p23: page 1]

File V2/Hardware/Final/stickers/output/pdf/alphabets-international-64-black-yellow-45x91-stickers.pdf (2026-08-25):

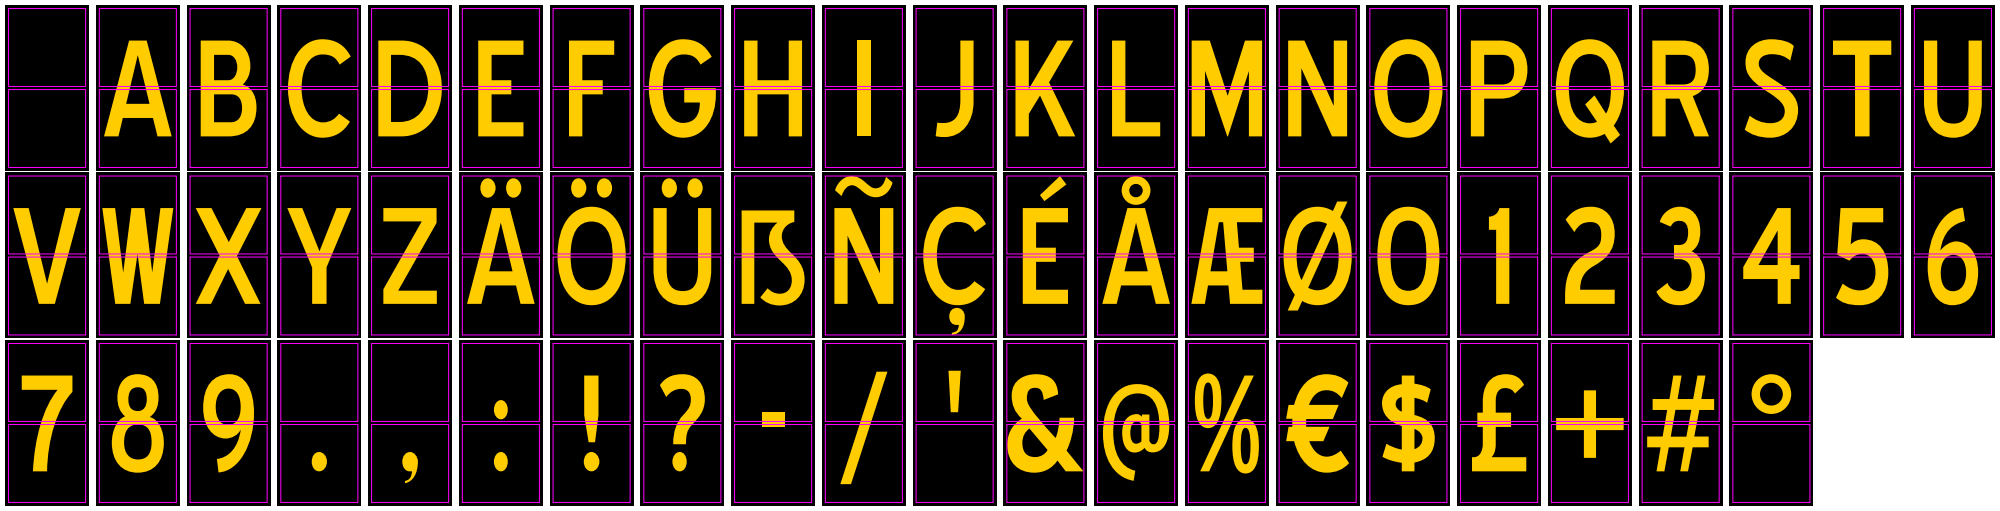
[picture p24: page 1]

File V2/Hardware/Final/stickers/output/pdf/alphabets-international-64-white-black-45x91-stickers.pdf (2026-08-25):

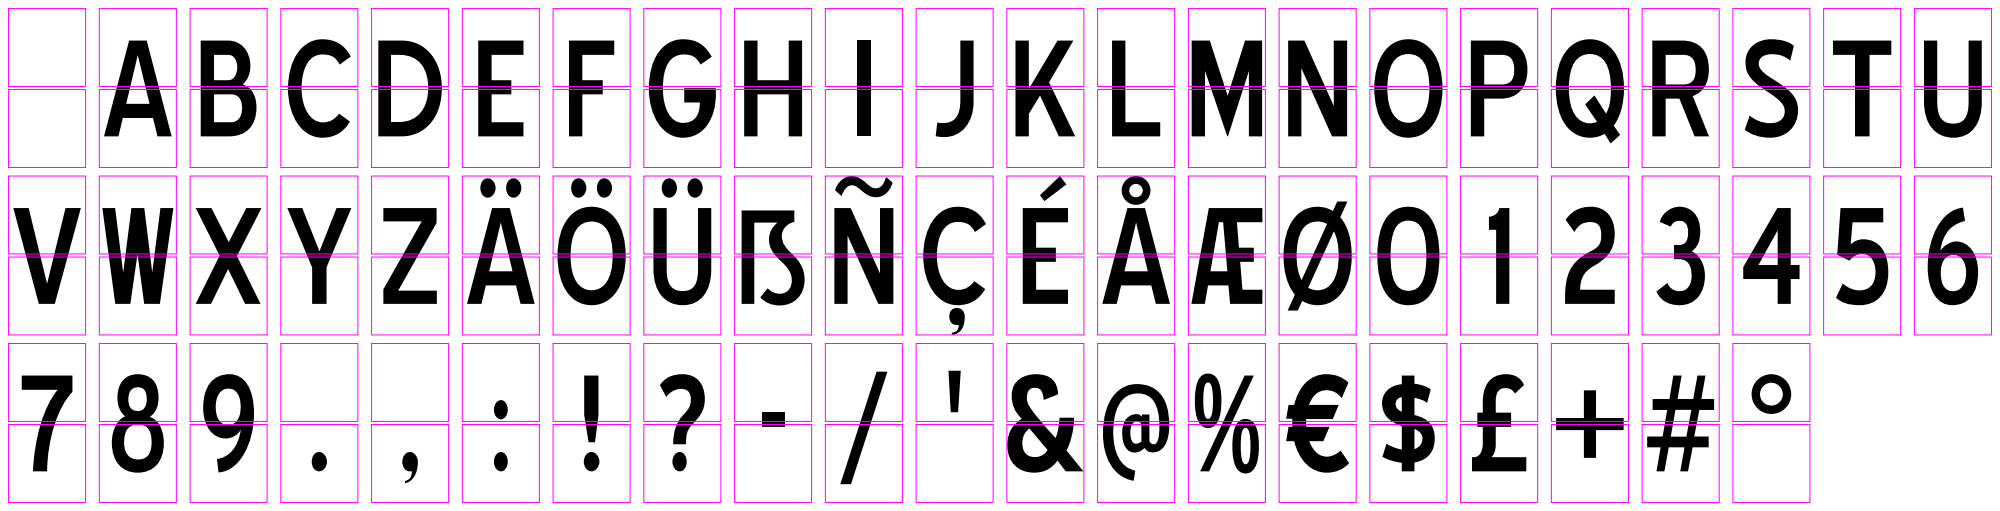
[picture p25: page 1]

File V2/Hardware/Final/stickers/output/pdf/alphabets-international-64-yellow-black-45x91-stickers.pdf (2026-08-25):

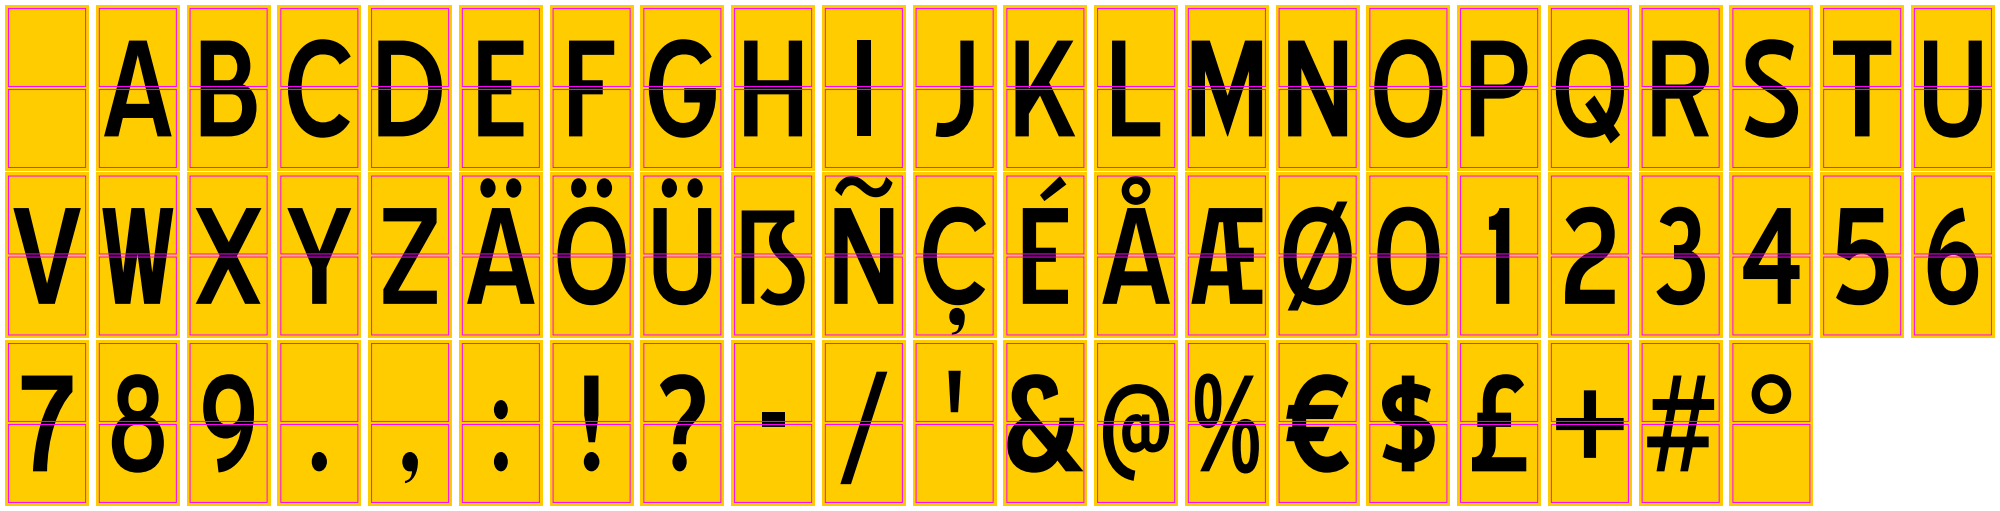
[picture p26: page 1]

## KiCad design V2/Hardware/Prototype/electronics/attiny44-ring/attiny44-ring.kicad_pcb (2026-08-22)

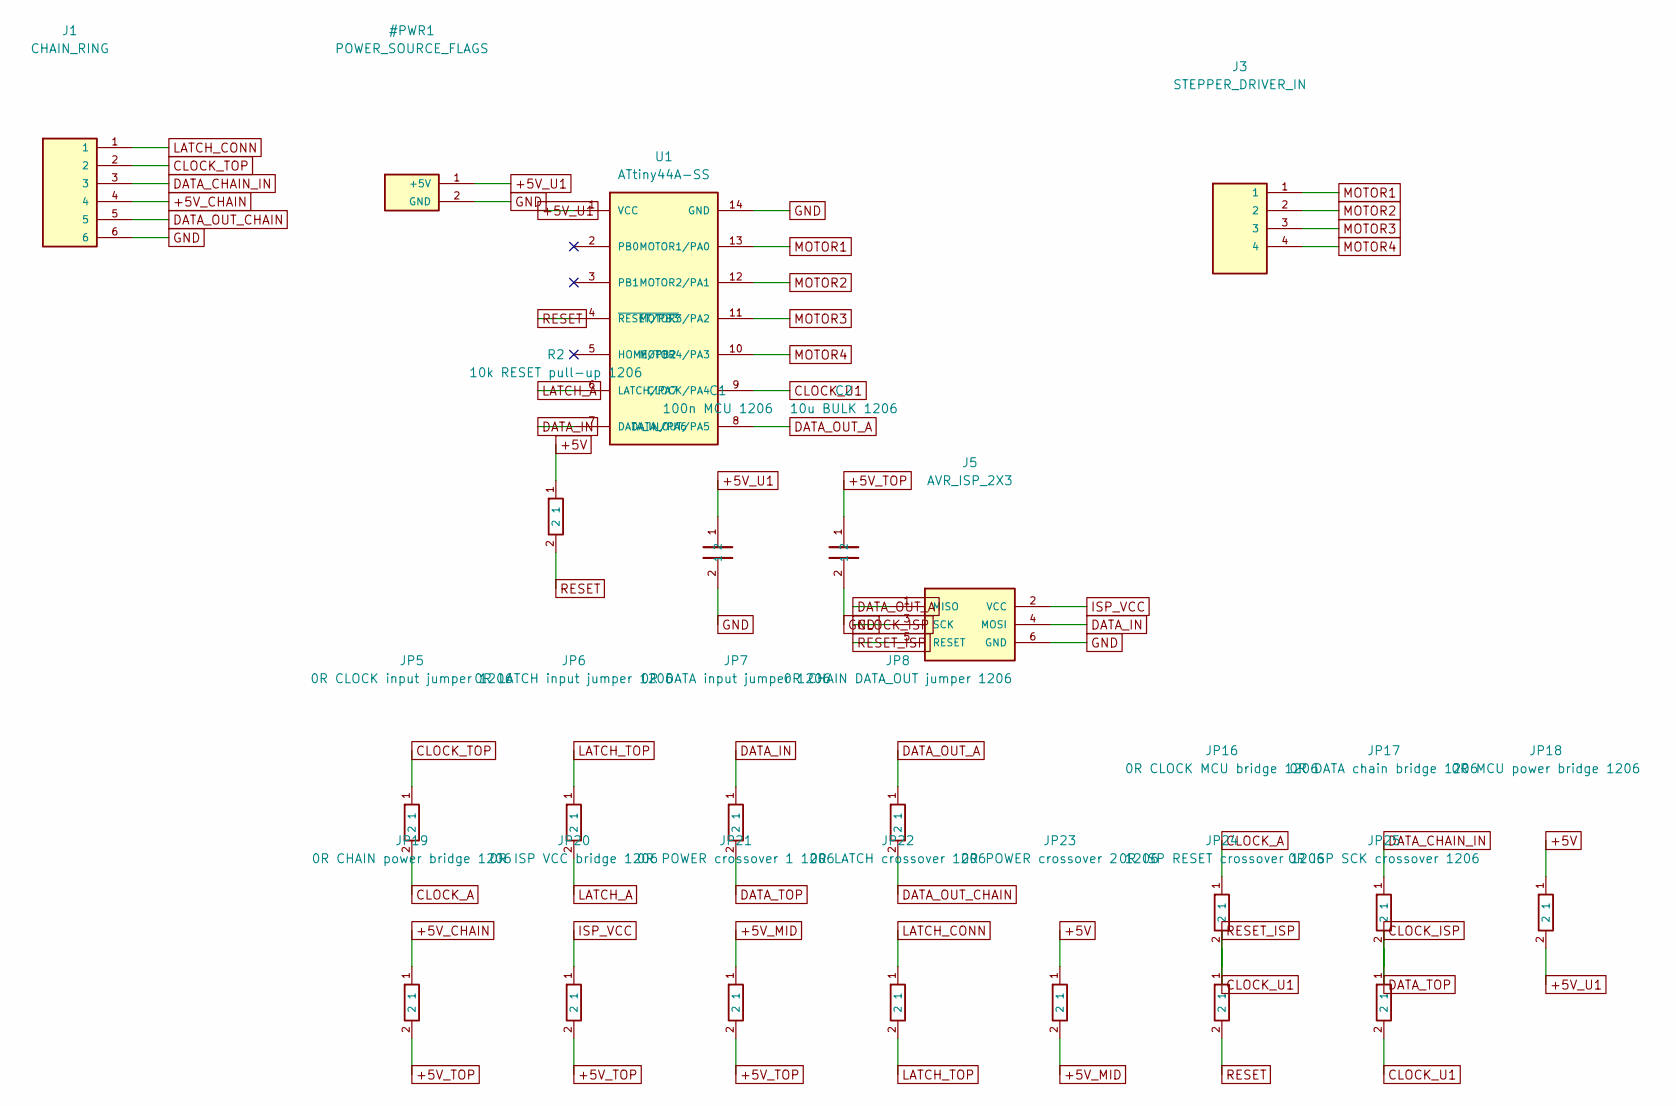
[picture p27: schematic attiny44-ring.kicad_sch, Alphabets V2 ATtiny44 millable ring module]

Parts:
C1: 100n MCU 1206; C_1206_3216Metric_Pad1.33x1.80mm_HandSolder
C2: 10u BULK 1206; C_1206_3216Metric_Pad1.33x1.80mm_HandSolder
J1: CHAIN_RING; PinHeader_2x03_P2.54mm_Vertical_SMD
J3: STEPPER_DRIVER_IN; PinHeader_1x04_P2.54mm_Vertical_SMD_Pin1Left
J5: AVR_ISP_2X3; PinHeader_2x03_P2.54mm_Vertical_SMD
JP5: 0R CLOCK input jumper 1206; R_1206_3216Metric_Pad1.30x1.75mm_HandSolder
JP6: 0R LATCH input jumper 1206; R_1206_3216Metric_Pad1.30x1.75mm_HandSolder
JP7: 0R DATA input jumper 1206; R_1206_3216Metric_Pad1.30x1.75mm_HandSolder
JP8: 0R CHAIN DATA_OUT jumper 1206; R_1206_3216Metric_Pad1.30x1.75mm_HandSolder
JP16: 0R CLOCK MCU bridge 1206; R_1206_3216Metric_Pad1.30x1.75mm_HandSolder
JP17: 0R DATA chain bridge 1206; R_1206_3216Metric_Pad1.30x1.75mm_HandSolder
JP18: 0R MCU power bridge 1206; R_1206_3216Metric_Pad1.30x1.75mm_HandSolder
JP19: 0R CHAIN power bridge 1206; R_1206_3216Metric_Pad1.30x1.75mm_HandSolder
JP20: 0R ISP VCC bridge 1206; R_1206_3216Metric_CompactCrossover
JP21: 0R POWER crossover 1 1206; R_1206_3216Metric_CompactCrossover
JP22: 0R LATCH crossover 1206; R_1206_3216Metric_CompactCrossover
JP23: 0R POWER crossover 2 1206; R_1206_3216Metric_CompactCrossover
JP24: 0R ISP RESET crossover 1206; R_1206_3216Metric_CompactCrossover
JP25: 0R ISP SCK crossover 1206; R_1206_3216Metric_CompactCrossover
R2: 10k RESET pull-up 1206; R_1206_3216Metric_Pad1.30x1.75mm_HandSolder
U1: ATtiny44A-SS; SOIC-14_3.9x8.7mm_P1.27mm

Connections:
+5V: JP18.1, JP23.1, R2.1
+5V_CHAIN: J1.4, JP19.1
+5V_MID: JP21.1, JP23.2
+5V_TOP: C2.1, JP19.2, JP20.2, JP21.2
CLOCK_A: JP5.2, JP16.1
CLOCK_ISP: J5.3 (SCK), JP25.1
CLOCK_TOP: J1.2, JP5.1
CLOCK_U1: JP16.2, JP25.2, U1.9 (CLOCK/PA4)
DATA_CHAIN_IN: J1.3, JP17.1
DATA_IN: J5.4 (MOSI), JP7.1, U1.7 (DATA_IN/PA6)
DATA_OUT_A: J5.1 (MISO), JP8.1, U1.8 (DATA_OUT/PA5)
DATA_OUT_CHAIN: J1.5, JP8.2
DATA_TOP: JP7.2, JP17.2
ISP_VCC: J5.2 (VCC), JP20.1
LATCH_A: JP6.2, U1.6 (LATCH/PA7)
LATCH_CONN: J1.1, JP22.1
LATCH_TOP: JP6.1, JP22.2
MOTOR1: J3.1, U1.13 (MOTOR1/PA0)
MOTOR2: J3.2, U1.12 (MOTOR2/PA1)
MOTOR3: J3.3, U1.11 (MOTOR3/PA2)
MOTOR4: J3.4, U1.10 (MOTOR4/PA3)
RESET: JP24.2, R2.2, U1.4 (~RESET/PB3)
RESET_ISP: J5.5 (RESET), JP24.1

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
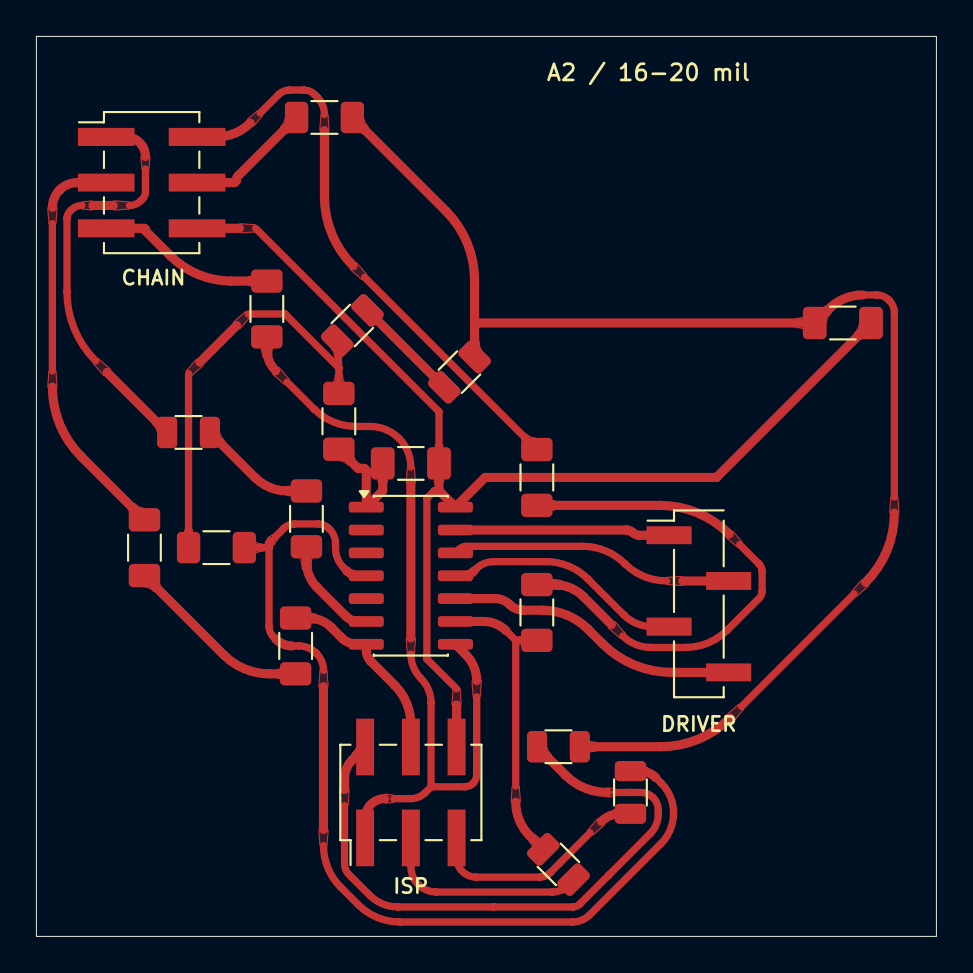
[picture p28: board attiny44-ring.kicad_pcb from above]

Board: 2 copper layers, 50.0 x 50.0 mm, 21 parts (0 on the bottom side), 25 nets.

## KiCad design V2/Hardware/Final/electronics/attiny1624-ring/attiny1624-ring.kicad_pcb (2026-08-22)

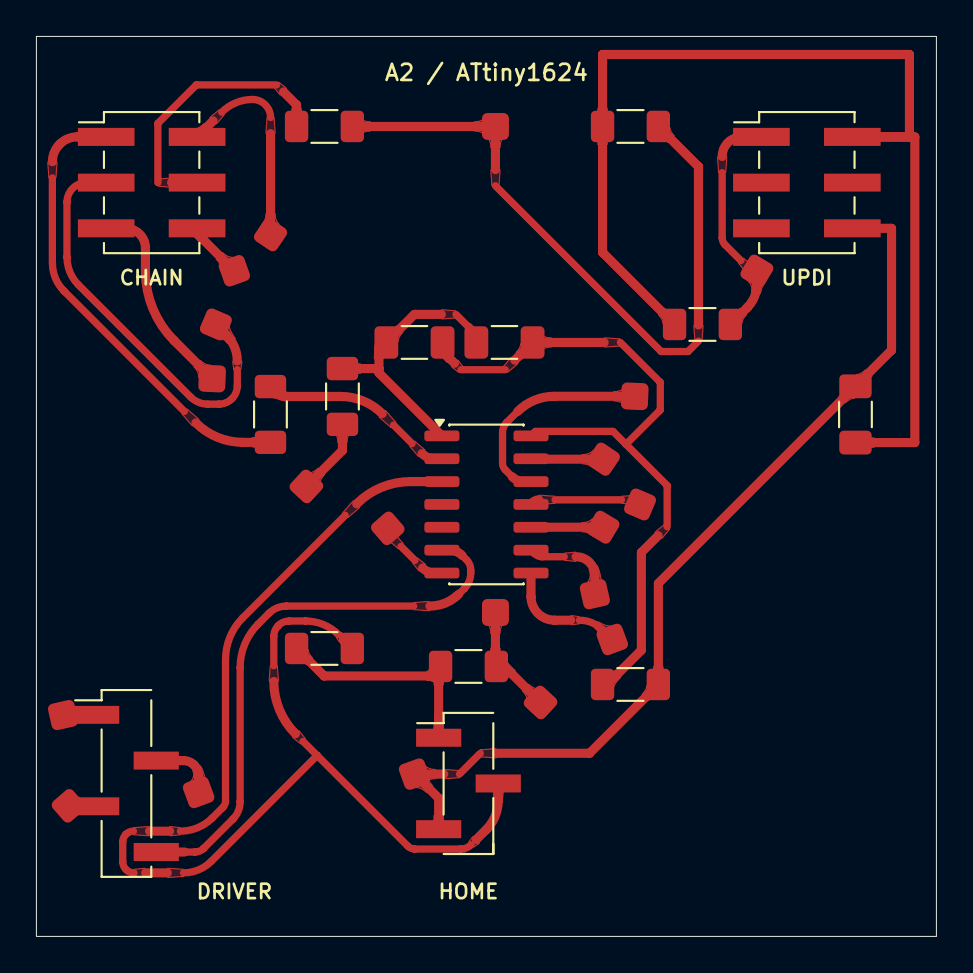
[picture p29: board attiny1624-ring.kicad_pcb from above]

Board: 2 copper layers, 50.0 x 50.0 mm, 26 parts (0 on the bottom side), 28 nets.

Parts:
C1: 100n MCU 1206; C_1206_3216Metric_Pad1.33x1.80mm_HandSolder
C2: 1n HF 1206; C_1206_3216Metric_Pad1.33x1.80mm_HandSolder
C3: 10u BULK 1206; C_1206_3216Metric_Pad1.33x1.80mm_HandSolder
J1: CHAIN_RING; PinHeader_2x03_P2.54mm_Vertical_SMD
J3: STEPPER_DRIVER_IN; PinHeader_1x04_P2.54mm_Vertical_SMD_Pin1Left
J4: HOME_SENSOR; PinHeader_1x03_P2.54mm_Vertical_SMD_Pin1Left
J5: UPDI_2X3; PinHeader_2x03_P2.54mm_Vertical_SMD
JP1: 0R CHAIN power bridge 1206; R_1206_3216Metric_Pad1.30x1.75mm_HandSolder
JP2: 0R UPDI power bridge 1206; R_1206_3216Metric_Pad1.30x1.75mm_HandSolder
JP3: 0R HOME power bridge 1206; R_1206_3216Metric_Pad1.30x1.75mm_HandSolder
JP4: 0R MCU power bridge 1206; R_1206_3216Metric_Pad1.30x1.75mm_HandSolder
JP5: INSULATED CLOCK LINK 22.3mm; WireLink_22.3mm_SMD
JP6: 0R LATCH bridge 1206; R_1206_3216Metric_Pad1.30x1.75mm_HandSolder
JP7: INSULATED DATA_IN LINK 25.6mm; WireLink_25.6mm_SMD
JP8: INSULATED DATA_OUT LINK 23.5mm; WireLink_23.5mm_SMD
JP9: 0R MCU ground bridge 1206; R_1206_3216Metric_Pad1.30x1.75mm_HandSolder
JP10: INSULATED UPDI LINK 16.6mm; WireLink_16.6mm_SMD
JP11: INSULATED GND LINK 29.7mm; WireLink_29.7mm_SMD
JP12: INSULATED MOTOR3 LINK 23.5mm; WireLink_23.5mm_SMD
JP13: INSULATED MCU POWER LINK 17.7mm; WireLink_17.7mm_SMD
JP14: INSULATED MOTOR1 LINK 30.3mm; WireLink_30.3mm_SMD
JP15: INSULATED MOTOR2 LINK 24.5mm; WireLink_24.5mm_SMD
JP16: INSULATED MAIN POWER LINK 27.0mm; WireLink_27.0mm_SMD
R1: 10k UPDI pull-up 1206; R_1206_3216Metric_Pad1.30x1.75mm_HandSolder
R2: 10k HOME pull-up 1206; R_1206_3216Metric_Pad1.30x1.75mm_HandSolder
U1: ATtiny1624-SSU; SOIC-14_3.9x8.7mm_P1.27mm

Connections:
+5V_CHAIN: J1.4, JP1.1
+5V_HOME: J4.1, JP3.1, R2.1
+5V_MAIN: JP3.2, JP13.1, JP16.2
+5V_MAIN_TOP: JP1.2, JP2.2, JP16.1
+5V_MCU_SOURCE: JP4.1, JP13.2
+5V_U1: C1.1, C2.1, JP4.2, U1.1
+5V_UPDI: C3.1, J5.2, JP2.1, R1.1
CLOCK_CONN: J1.2, JP5.1
CLOCK_U1: JP5.2, U1.13
DATA_CHAIN_IN: J1.3, JP7.1
DATA_IN_U1: JP7.2, U1.11
DATA_OUT_CHAIN: J1.5, JP8.2
DATA_OUT_U1: JP8.1, U1.12
GND: C3.2, J4.3, J5.6, JP9.2, JP11.2
GND_CHAIN: J1.6, JP11.1
GND_U1: C1.2, C2.2, JP9.1, U1.14
HOME: J4.2, R2.2, U1.3
LATCH_CONN: J1.1, JP6.1
LATCH_U1: JP6.2, U1.2
MOTOR1_DRIVER: J3.1, JP14.2
MOTOR1_U1: JP14.1, U1.9
MOTOR2_DRIVER: J3.2, JP15.2
MOTOR2_U1: JP15.1, U1.8
MOTOR3_DRIVER: J3.3, JP12.2
MOTOR3_U1: JP12.1, U1.7
MOTOR4: J3.4, U1.6
UPDI_PROG: J5.1, JP10.1, R1.2
UPDI_U1: JP10.2, U1.10

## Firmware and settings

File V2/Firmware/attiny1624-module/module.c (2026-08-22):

// SPDX-FileCopyrightText: 2014-2026 The Beach Lab <https://beachlab.org>
// SPDX-License-Identifier: MIT
#include <avr/eeprom.h>
#include <avr/interrupt.h>
#include <avr/io.h>
#include <avr/sleep.h>
#include <stdbool.h>
#include <stdint.h>
#include <util/atomic.h>

#include "protocol_core.h"

#ifndef F_CPU
#define F_CPU 20000000UL
#endif

#ifndef MOTOR_HALF_STEPS_PER_REVOLUTION
#define MOTOR_HALF_STEPS_PER_REVOLUTION 4096UL
#endif

#ifndef MOTOR_STEP_HZ
#define MOTOR_STEP_HZ 500UL
#endif

#ifndef MOTOR_REVERSED
#define MOTOR_REVERSED 0
#endif

#ifndef HOMING_MAX_REVOLUTIONS
#define HOMING_MAX_REVOLUTIONS 2UL
#endif

#ifndef HOME_ACTIVE_CONFIRM_STEPS
#define HOME_ACTIVE_CONFIRM_STEPS 2u
#endif

#define MOTOR_MASK 0x0fu
#define MOTOR_TIMER_CLOCK_HZ (F_CPU / 2UL)
#define MOTOR_TIMER_COMPARE_VALUE \
    ((MOTOR_TIMER_CLOCK_HZ / MOTOR_STEP_HZ) - 1UL)
#define HOMING_MAX_HALF_STEPS \
    (MOTOR_HALF_STEPS_PER_REVOLUTION * HOMING_MAX_REVOLUTIONS)
#define EEPROM_RECORD_COUNT 32u
#define EEPROM_RECORD_COMMITTED 0x5au
#define EEPROM_POSITION_UNKNOWN 0xffu

#if F_CPU != 20000000UL
#error "This firmware expects the ATtiny1624 internal 20 MHz clock"
#endif

#if MOTOR_HALF_STEPS_PER_REVOLUTION < MODULE_POSITION_COUNT
#error "MOTOR_HALF_STEPS_PER_REVOLUTION must be at least 64"
#endif

#if MOTOR_HALF_STEPS_PER_REVOLUTION > 65535UL
#error "MOTOR_HALF_STEPS_PER_REVOLUTION must fit in uint16_t"
#endif

#if HOMING_MAX_HALF_STEPS > 65535UL
#error "The homing travel limit must fit in uint16_t"
#endif

#if HOME_ACTIVE_CONFIRM_STEPS < 1u || HOME_ACTIVE_CONFIRM_STEPS > 255u
#error "HOME_ACTIVE_CONFIRM_STEPS must fit in uint8_t and be at least one"
#endif

#if MOTOR_TIMER_COMPARE_VALUE > 65535UL
#error "MOTOR_STEP_HZ is too low for TCB0 with a /2 clock"
#endif

#if MOTOR_TIMER_COMPARE_VALUE < 1UL
#error "MOTOR_STEP_HZ is too high for TCB0 with a /2 clock"
#endif

static const uint8_t motor_half_step_sequence[8] = {
    0x01u,
    0x03u,
    0x02u,
    0x06u,
    0x04u,
    0x0cu,
    0x08u,
    0x09u,
};

static volatile module_state_t module_state;

static volatile bool frame_active;
static volatile bool frame_received_byte;
static volatile bool latch_was_high;
static volatile uint8_t frame_last_byte;
static volatile bool command_pending;
static volatile uint8_t pending_command;

static volatile uint8_t motor_phase_index;
static volatile uint16_t half_steps_remaining;
static volatile uint8_t home_active_samples;

typedef struct {
    uint8_t sequence;
    uint8_t position;
    uint8_t check;
    uint8_t committed;
} position_record_t;

_Static_assert(sizeof(position_record_t) == 4u, "EEPROM record must be four bytes");

static position_record_t EEMEM eeprom_position_records[EEPROM_RECORD_COUNT];
static uint8_t last_eeprom_sequence = 0xffu;

static uint8_t position_check(uint8_t sequence, uint8_t position)
{
    return sequence ^ position ^ 0xa5u;
}

static bool load_stored_position(uint8_t *position)
{
    position_record_t newest = {0u, EEPROM_POSITION_UNKNOWN, 0u, 0u};
    bool found = false;

    for (uint8_t slot = 0u; slot < EEPROM_RECORD_COUNT; ++slot) {
        position_record_t candidate;

        eeprom_read_block(
            &candidate,
            &eeprom_position_records[slot],
            sizeof(candidate)
        );

        if (candidate.committed != EEPROM_RECORD_COMMITTED
            || candidate.check
                != position_check(candidate.sequence, candidate.position)) {
            continue;
        }

        if (!found
            || module_sequence_is_newer(candidate.sequence, newest.sequence)) {
            newest = candidate;
            found = true;
        }
    }

    if (!found) {
        return false;
    }

    last_eeprom_sequence = newest.sequence;
    if (newest.position >= MODULE_POSITION_COUNT) {
        return false;
    }

    *position = newest.position;
    return true;
}

static void append_position_record(uint8_t position)
{
    const uint8_t sequence = last_eeprom_sequence + 1u;
    position_record_t *record =
        &eeprom_position_records[sequence % EEPROM_RECORD_COUNT];

    eeprom_update_byte(&record->committed, 0u);
    eeprom_update_byte(&record->sequence, sequence);
    eeprom_update_byte(&record->position, position);
    eeprom_update_byte(&record->check, position_check(sequence, position));
    eeprom_update_byte(&record->committed, EEPROM_RECORD_COMMITTED);
    last_eeprom_sequence = sequence;
}

static void invalidate_stored_position(void)
{
    append_position_record(EEPROM_POSITION_UNKNOWN);
}

static void persist_current_position(void)
{
    uint8_t position;

    ATOMIC_BLOCK(ATOMIC_RESTORESTATE) {
        position = module_state.current_position;
    }

    append_position_record(position);

    ATOMIC_BLOCK(ATOMIC_RESTORESTATE) {
        module_mark_persisted(&module_state);
    }
}

static bool home_sensor_is_active(void)
{
    return (VPORTA.IN & PIN5_bm) == 0u;
}

static void motor_write_phase(uint8_t phase)
{
    VPORTB.OUT = (VPORTB.OUT & (uint8_t)~MOTOR_MASK)
        | (phase & MOTOR_MASK);
}

static void motor_release(void)
{
    TCB0.CTRLA = 0u;
    motor_write_phase(0u);
}

static void motor_timer_start(void)
{
    motor_write_phase(motor_half_step_sequence[motor_phase_index]);
    TCB0.CNT = 0u;
    TCB0.INTFLAGS = TCB_CAPT_bm;
    TCB0.CTRLA = TCB_CLKSEL_DIV2_gc | TCB_ENABLE_bm;
}

static void motor_start_position(void)
{
    uint8_t current_position;

    ATOMIC_BLOCK(ATOMIC_RESTORESTATE) {
        current_position = module_state.current_position;
    }

    half_steps_remaining = module_half_steps_to_next_position(
        current_position,
        (uint16_t)MOTOR_HALF_STEPS_PER_REVOLUTION
    );
    motor_timer_start();
}

static void motor_start_home(void)
{
    half_steps_remaining = (uint16_t)HOMING_MAX_HALF_STEPS;
    home_active_samples = 0u;
    module_home_observe(&module_state, home_sensor_is_active());
    motor_timer_start();
}

static void configure_clock(void)
{
    _PROTECTED_WRITE(CLKCTRL.MCLKCTRLB, 0u);
}

static void configure_io(void)
{
    PORTA.DIRCLR = PIN1_bm | PIN3_bm | PIN4_bm | PIN5_bm;
    PORTA.DIRSET = PIN2_bm;
    PORTA.OUTCLR = PIN2_bm;
    PORTA.PIN4CTRL = PORT_ISC_BOTHEDGES_gc;
    PORTA.PIN5CTRL = PORT_PULLUPEN_bm;
    PORTA.INTFLAGS = PIN4_bm;

    PORTB.DIRSET = MOTOR_MASK;
    PORTB.OUTCLR = MOTOR_MASK;
}

static void configure_spi(void)
{
    SPI0.CTRLA = 0u;
    SPI0.CTRLB = SPI_MODE_0_gc;
    SPI0.DATA = 0u;
    SPI0.INTFLAGS = SPI_IF_bm;
    SPI0.INTCTRL = SPI_IE_bm;
    SPI0.CTRLA = SPI_ENABLE_bm;
}

static void configure_latch_interrupt(void)
{
    latch_was_high = (VPORTA.IN & PIN4_bm) != 0u;
    PORTA.INTFLAGS = PIN4_bm;
}

static void configure_motor_timer(void)
{
    TCB0.CTRLA = 0u;
    TCB0.CTRLB = TCB_CNTMODE_INT_gc;
    TCB0.CNT = 0u;
    TCB0.CCMP = (uint16_t)MOTOR_TIMER_COMPARE_VALUE;
    TCB0.INTFLAGS = TCB_CAPT_bm;
    TCB0.INTCTRL = TCB_CAPT_bm;
}

static bool take_pending_command(uint8_t *command)
{
    bool available;

    ATOMIC_BLOCK(ATOMIC_RESTORESTATE) {
        available = command_pending;
        if (available) {
            *command = pending_command;
            command_pending = false;
        }
    }

    return available;
}

static void process_command(uint8_t command)
{
    module_command_result_t result;

    ATOMIC_BLOCK(ATOMIC_RESTORESTATE) {
        result = module_apply_command(&module_state, command);
    }

    if (result == MODULE_COMMAND_START_MOTION
        || result == MODULE_COMMAND_START_HOME) {
        invalidate_stored_position();
    }

    if (result == MODULE_COMMAND_START_MOTION) {
        motor_start_position();
    } else if (result == MODULE_COMMAND_START_HOME) {
        motor_start_home();
    }
}

ISR(PORTA_PORT_vect)
{
    const uint8_t interrupt_flags = PORTA.INTFLAGS;
    const bool latch_is_high = (VPORTA.IN & PIN4_bm) != 0u;

    PORTA.INTFLAGS = interrupt_flags;

    if ((interrupt_flags & PIN4_bm) == 0u
        || latch_is_high == latch_was_high) {
        return;
    }
    latch_was_high = latch_is_high;

    if (!latch_is_high) {
        frame_active = true;
        frame_received_byte = false;
        frame_last_byte = 0u;
        SPI0.DATA = module_build_status(&module_state);
        SPI0.INTFLAGS = SPI_IF_bm;
        return;
    }

    if (!frame_active) {
        return;
    }

    frame_active = false;
    if (frame_received_byte) {
        pending_command = frame_last_byte;
        command_pending = true;
    }
}

ISR(SPI0_INT_vect)
{
    const uint8_t received = SPI0.DATA;

    if (frame_active) {
        frame_last_byte = received;
        frame_received_byte = true;
        SPI0.DATA = received;
    } else {
        SPI0.DATA = 0u;
    }

    SPI0.INTFLAGS = SPI_IF_bm;
}

ISR(TCB0_INT_vect)
{
    TCB0.INTFLAGS = TCB_CAPT_bm;

#if MOTOR_REVERSED
    motor_phase_index = (motor_phase_index + 7u) & 0x07u;
#else
    motor_phase_index = (motor_phase_index + 1u) & 0x07u;
#endif
    motor_write_phase(motor_half_step_sequence[motor_phase_index]);

    if (module_is_homing(&module_state)) {
        const bool home_active = home_sensor_is_active();

        if (!home_active) {
            home_active_samples = 0u;
            module_home_observe(&module_state, false);
        } else if (home_active_samples < HOME_ACTIVE_CONFIRM_STEPS) {
            ++home_active_samples;
        }

        if (home_active_samples >= HOME_ACTIVE_CONFIRM_STEPS
            && module_home_observe(&module_state, true)) {
            motor_release();
            return;
        }

        if (--half_steps_remaining == 0u) {
            module_home_failed(&module_state);
            motor_release();
        }
        return;
    }

    if (--half_steps_remaining != 0u) {
        return;
    }

    if (module_reached_next_position(&module_state)) {
        motor_release();
        return;
    }

    half_steps_remaining =
        module_half_steps_to_next_position(
            module_state.current_position,
            (uint16_t)MOTOR_HALF_STEPS_PER_REVOLUTION
        );
}

static void sleep_until_work(void)
{
    cli();
    if (!command_pending
        && !(module_needs_persist(&module_state)
            && !module_is_moving(&module_state))) {
        sleep_enable();
        sei();
        sleep_cpu();
        sleep_disable();
        return;
    }
    sei();
}

int main(void)
{
    uint8_t stored_position = 0u;
    uint8_t command;
    const bool stored_position_is_valid = load_stored_position(&stored_position);

    configure_clock();
    configure_io();
    module_state_init(&module_state, stored_position, stored_position_is_valid);
    motor_release();
    configure_motor_timer();
    configure_spi();
    configure_latch_interrupt();

    set_sleep_mode(SLEEP_MODE_IDLE);
    sei();

    for (;;) {
        if (take_pending_command(&command)) {
            process_command(command);
        }

        if (module_needs_persist(&module_state)
            && !module_is_moving(&module_state)) {
            persist_current_position();
        }

        sleep_until_work();
    }
}

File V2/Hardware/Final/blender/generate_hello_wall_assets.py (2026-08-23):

#!/usr/bin/env python3
# SPDX-FileCopyrightText: 2014-2026 The Beach Lab <https://beachlab.org>
# SPDX-License-Identifier: MIT
"""Prepare exact CAD references and metadata for the HALLO/WELT! scene."""

from __future__ import annotations

import json
import sys
from pathlib import Path
from typing import Any

BLENDER_DIR = Path(__file__).resolve().parent
REPOSITORY_ROOT = BLENDER_DIR.parents[3]
MECHANICAL_DIR = BLENDER_DIR.parent / "mechanical"
OUTPUT_DIR = BLENDER_DIR / "generated/hello-wall"
LICENSES_DIR = REPOSITORY_ROOT / "LICENSES"
COMPONENTS_DIR = OUTPUT_DIR / "components"
CAPTURE_PATH = BLENDER_DIR / "generated/cards-position-capture.json"
ENCLOSURE_MANIFEST_PATH = MECHANICAL_DIR / "generated/captured-enclosure/manifest.json"
STICKER_MAPPING_PATH = BLENDER_DIR / "generated/sticker-mapping.json"
FONT_PATH = BLENDER_DIR.parent / "stickers/fonts/BlueHighwayD-International.otf"
ROWS = ("HALLO", "WELT!")
BACKGROUND_RGB = (2, 3, 4)
LETTER_RGB = (255, 204, 0)
MOTOR_COMPONENTS = ("motor_body", "motor_collar", "motor_backpack", "motor_shaft")

if str(MECHANICAL_DIR) not in sys.path:
    sys.path.insert(0, str(MECHANICAL_DIR))
if str(LICENSES_DIR) not in sys.path:
    sys.path.insert(0, str(LICENSES_DIR))

from alphabets_cad.assemblies import captured_enclosure_design_components
from alphabets_cad.parameters import DESIGN
from json_license_metadata import validate_json_license, write_licensed_json


def load_json(path: Path) -> dict[str, Any]:
    data = json.loads(path.read_text(encoding="utf-8"))
    validate_json_license(data, str(path))
    return data


def _round_vector(*values: float) -> list[float]:
    return [round(value, 9) for value in values]


def _character_uv(character: str) -> dict[str, dict[str, object]]:
    assignments = load_json(STICKER_MAPPING_PATH)["assignments"]
    matches = [item for item in assignments if item["character"] == character]
    if len(matches) != 2:
        raise RuntimeError(f"expected two production-atlas halves for {character!r}")
    return {
        item["display_half"]: {
            "uv_box": item["uv_box"],
            "rotation_degrees": item["rotation_degrees"],
            "horizontal_flip": item["horizontal_flip"],
            "character_index": item["character_index"],
        }
        for item in matches
    }


def _fastener_layout(
    limits: dict[str, float], enclosure: dict[str, float], capture: dict[str, Any]
) -> list[dict[str, object]]:
    front_y = limits["front_y"]
    outer_x_min = limits["outer_x_min"]
    recessed_motor_face_x = outer_x_min + enclosure["motor_inset_depth"]
    pawl_bounds = capture["pawl"]["bounds_world_mm"]
    pawl_thickness = (
        float(pawl_bounds["maximum"][1])
        - float(pawl_bounds["minimum"][1])
        + enclosure["pawl_thickness_addition"]
    )
    pawl_outer_y = front_y + pawl_thickness
    pawl_axis_z = (limits["inner_top_z"] + limits["outer_top_z"]) / 2
    pawl_head_depth = enclosure["pawl_head_recess_depth"]
    pawl_shaft_outer = pawl_outer_y - pawl_head_depth
    pawl_shaft_inner = front_y - enclosure["pawl_pilot_depth"]

    shaft_recess_face_x = limits["outer_x_max"] - enclosure["docking_recess_depth"]
    shaft_head_depth = enclosure["shaft_head_recess_depth"]
    shaft_outer = shaft_recess_face_x - shaft_head_depth
    shaft_inner = DESIGN.drum_outer_width / 2 - DESIGN.drum.side_thickness

    motor_bracket_outer_x = recessed_motor_face_x - DESIGN.motor.mount_bracket_height
    motor_head_depth = 2.0
    motor_shaft_inner = (
        -DESIGN.drum_outer_width / 2 - enclosure["motor_mount_disc_clearance"]
    )

    def screw(
        name: str,
        axis: str,
        head_diameter: float,
        head_depth: float,
        head_center: tuple[float, float, float],
        slot_center: tuple[float, float, float],
        shaft_start: tuple[float, float, float],
        shaft_end: tuple[float, float, float],
    ) -> dict[str, object]:
        axis_index = {"X": 0, "Y": 1, "Z": 2}[axis]
        shaft_depth = abs(shaft_end[axis_index] - shaft_start[axis_index])
        shaft_center = tuple(
            (shaft_start[index] + shaft_end[index]) / 2 for index in range(3)
        )
        return {
            "name": name,
            "axis": axis,
            "nominal": "M3",
            "head_diameter_mm": head_diameter,
            "head_depth_mm": head_depth,
            "head_center_mm": _round_vector(*head_center),
            "slot_center_mm": _round_vector(*slot_center),
            "shaft_diameter_mm": 3.0,
            "shaft_depth_mm": round(shaft_depth, 9),
            "shaft_center_mm": _round_vector(*shaft_center),
        }

    fasteners = [
        screw(
            "pawl",
            "Y",
            enclosure["pawl_head_recess_diameter"],
            pawl_head_depth,
            (0, pawl_outer_y - pawl_head_depth / 2, pawl_axis_z),
            (0, pawl_outer_y + 0.01, pawl_axis_z),
            (0, pawl_shaft_outer, pawl_axis_z),
            (0, pawl_shaft_inner, pawl_axis_z),
        ),
        screw(
            "axle",
            "X",
            enclosure["shaft_head_recess_diameter"],
            shaft_head_depth,
            (shaft_recess_face_x - shaft_head_depth / 2, 0, 0),
            (shaft_recess_face_x + 0.01, 0, 0),
            (shaft_outer, 0, 0),
            (shaft_inner, 0, 0),
        ),
    ]
    for side, mount_y in (
        ("negative_y", -DESIGN.motor.mount_center_offset),
        ("positive_y", DESIGN.motor.mount_center_offset),
    ):
        fasteners.append(
            screw(
                f"motor_{side}",
                "X",
                6.2,
                motor_head_depth,
                (
                    motor_bracket_outer_x - motor_head_depth / 2,
                    mount_y,
                    -DESIGN.motor.shaft_offset,
                ),
                (
                    motor_bracket_outer_x - motor_head_depth - 0.01,
                    mount_y,
                    -DESIGN.motor.shaft_offset,
                ),
                (
                    motor_bracket_outer_x,
                    mount_y,
                    -DESIGN.motor.shaft_offset,
                ),
                (
                    motor_shaft_inner,
                    mount_y,
                    -DESIGN.motor.shaft_offset,
                ),
            )
        )
    return fasteners
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

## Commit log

2014-10-02 Changes in lock
    Made it solid because breaks easily. Also increased length by 1 mm
    because some cards get stuck
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2014-12-26 Fixed W character. Working on V2 wheels
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2017-02-12 starting port to freecad
    [card.fcstd, gear-card.fcstd]
2018-01-17 hello alphabets
    [card.fcstd, gear-card.fcstd]
2018-12-06 2018 changes
    [28byj48.scad, card.fcstd, gear-card.fcstd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]
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2025-11-18 Change to TBL laser
    [spool.scad]
2025-11-18 prepare to create new enclosure
    [side_motor.FCStd, spool.scad]
2025-11-19 fix card extrude and prepare new enclosure
    [card.fcstd, side_motor.FCStd]
2026-08-15 Update side motor FreeCAD model backup
    [side_motor.FCStd]
2026-08-15 Add ATtiny44 V2 serial ring board
    [attiny44-ring-B_Cu.gbl, attiny44-ring-B_Mask.gbs, attiny44-ring-B_Silkscreen.gbo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]
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2026-08-15 Redesign ATtiny44 ring board for milling
    [attiny44-ring-B_Cu.gbl, attiny44-ring-B_Mask.gbs, attiny44-ring-B_Silkscreen.gbo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]
2026-08-17 Compact ATtiny44 ring PCB to 50x57 mm
    [attiny44-ring-bom.csv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]
2026-08-17 Place ISP beside ATtiny44 on compact board
    [attiny44-ring-bom.csv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]
2026-08-18 Add organic wide-track ATtiny44 board finish
    [attiny44-ring.dsn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]
2026-08-18 Adapt organic trace radii and width tapers
    [attiny44-ring.dsn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]
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2026-08-18 Match card and drum to 50 mm stickers
    [card-50x48-cut.dxf, card-50x48.fcstd, spool-50mm.dxf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]
2026-08-19 Port V2 mechanics to CadQuery
    [drum-assembly.step, drum-complete-layout.dxf, drum-motor-side.dxf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]
2026-08-19 Add ATtiny1624 ring module board
    [attiny1624-ring-bom.csv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]
2026-08-19 Add printable two-part drum enclosure
    [drum-enclosure-assembly.step, drum-enclosure-lower.step, drum-enclosure-lower.stl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]
2026-08-19 Align ATtiny1624 board with module firmware
    [attiny1624-ring-bom.csv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]
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2026-08-21 Mount stopped cards in enclosure reference
    [enclosed-module-reference.step]
2026-08-21 Align stopped cards and motor shaft
    [enclosed-module-reference.step]
2026-08-21 Place card 63 below the stopped display
    [enclosed-module-reference.step]
2026-08-21 Center card thickness on drum pivot axes
    [enclosed-module-reference.step]
2026-08-21 Keep stopped cards 31 and 32 vertical
    [enclosed-module-reference.step]
2026-08-21 Size definitive card tabs for pivot rotation
    [card-50x48-cut.dxf, card-50x48.fcstd, enclosed-module-reference.step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]
2026-08-21 Model card stickers with placement margins
    [card-50x48.fcstd, card-cut.dxf, card.fcstd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]
2026-08-21 Correct full visible card height semantics
    [card-50x48.fcstd, card.fcstd]
2026-08-21 Align stickers to card hinge edge
    [card-50x48.fcstd, card.fcstd, enclosed-module-reference.step]
2026-08-21 Arrange and relabel cards for gravity setup
    [enclosed-module-reference.step]
2026-08-21 Add interactive Blender drum simulation
    [alphabets-v2-interactive.blend, alphabets-v2-pawl-layout-flat-pawl-v2.blend, motor_backpack.stl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]
2026-08-21 Flip lower sticker artwork horizontally
    [alphabets-v2-interactive.blend]
2026-08-21 Improve interactive Blender drum controls
    [alphabets-v2-interactive.blend]
2026-08-21 Keep cards black in Blender review
    [alphabets-v2-interactive.blend]
2026-08-21 Size enclosure from captured card envelope
    [drum-enclosure-assembly.step, drum-enclosure-lower.step, drum-enclosure-lower.stl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]
2026-08-22 Add long-running Blender drum simulation
    [alphabets-v2-long-run.blend]
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2026-08-22 Clarify MIT licensing and attribution
    [connector.scad, spool-3dp.scad, spool-holder.scad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]
2026-08-22 Add licensing metadata to every file
    [28byj48.scad, alphabets-v2-interactive.blend, alphabets-v2-pawl-layout-flat-pawl-v2.blend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]
2026-08-22 Embed license metadata in project artifacts
    [alphabets-v2-interactive.blend, alphabets-v2-pawl-layout-flat-pawl-v2.blend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]
2026-08-22 Add captured parametric enclosure and print plate
    [captured-enclosure-assembly.step, captured-enclosure-bambu-a1-mini-four-part-plate.stl, captured-enclosure-lower.step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]
2026-08-22 Add HALLO WELT Blender module wall
    [alphabets-hallo-welt-5x2.blend]
2026-08-22 Replace mock wall with complete Alphabets modules
    [generate_hello_wall_assets.py]
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2026-08-23 Separate complete V2 prototype and final designs
    [alphabets-hallo-welt-5x2.blend, alphabets-v2-final.blend, alphabets-v2-interactive.blend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]
2026-08-23 Correct V2 prototype pawl reach
    [captured-enclosure-assembly.step, captured-enclosure-pawl.step, captured-enclosure-pawl.stl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]
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2026-08-23 Align prototype card poses and shorten pawl
    [captured-enclosure-assembly.step, captured-enclosure-lower.step, captured-enclosure-lower.stl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]
2026-08-23 Revert recent V2 prototype and pawl changes
    [alphabets-hallo-welt-5x2.blend, alphabets-v2-final.blend, alphabets-v2-interactive.blend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]
2026-08-23 Reorganize V2 sources and add guided documentation
    [28byj48.scad, alphabets-v2-interactive.blend, alphabets-v2-pawl-layout-flat-pawl-v2.blend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]
2026-08-23 Retire stale enclosure model and document printed source
    [drum-enclosure-assembly.step, drum-enclosure-lower.step, drum-enclosure-lower.stl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]
2026-08-23 Add isolated V2 Prototype CAD package
    [captured-enclosure-assembly.step, captured-enclosure-bambu-a1-mini-prototype-plate.stl, captured-enclosure-lower.step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]
2026-08-24 Make Prototype enclosure controls drum-centred
    [captured-enclosure-assembly.step, captured-enclosure-bambu-a1-mini-prototype-plate.stl, captured-enclosure-lower.step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]
2026-08-24 Fix Prototype card tab-axis alignment
2026-08-24 Make Prototype enclosure one piece
    [captured-enclosure-assembly.step, captured-enclosure-bambu-a1-mini-prototype-plate.stl, captured-enclosure-lower.step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]
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2026-08-24 Fix one-piece enclosure viewer group
2026-08-24 Remove Prototype stacking magnets
    [captured-enclosure-assembly.step, captured-enclosure-bambu-a1-mini-prototype-plate.stl, captured-enclosure.step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]
2026-08-24 Fix Prototype viewer motor group
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2026-08-24 Add full-face Prototype side pockets
    [captured-enclosure-assembly.step, captured-enclosure-bambu-a1-mini-prototype-plate.stl, captured-enclosure-pawl-prototype.step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]
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2026-08-25 Correct V2 documentation diagrams and Prototype stickers
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2026-08-28 Remove Prototype pawl head recess
    [captured-enclosure-assembly.step, captured-enclosure-bambu-a1-mini-prototype-plate.stl, captured-enclosure-pawl-prototype.step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]
